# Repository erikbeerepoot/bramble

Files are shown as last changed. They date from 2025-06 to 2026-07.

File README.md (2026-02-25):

# Bramble

LoRa sensor and actuator network for farm monitoring, built on RP2040.

Hub-and-spoke architecture: a central hub manages the network while nodes collect sensor data (temperature, humidity) and control actuators (irrigation valves). LoRa provides long-range wireless with reliable delivery guarantees.

## Hardware

- Adafruit Feather RP2040 LoRa (SX1276, 915 MHz)
- MT25QL01GBBB 128MB external flash for sensor data storage
- STM32L010 PMU for power management and sleep

## Building

Requires the Pico SDK. CMake is bundled at `~/.pico-sdk/cmake/v3.31.5/bin/cmake`.

```bash
# Build a specific variant
cmake -B build -DHARDWARE_VARIANT=SENSOR
cmake --build build -j8

# Variants: SENSOR, IRRIGATION, CONTROLLER, HUB, GENERIC, ALL
```

Each variant produces a named executable (e.g. `bramble_sensor.uf2`).

```bash
# Run tests
cmake -B build -DBUILD_TESTS=ON
cmake --build build -j8
```

### Flashing

Hold BOOTSEL and connect via USB, then copy the `.uf2` file. Or use OpenOCD with a debug probe:

```bash
~/.pico-sdk/openocd/0.12.0+dev/openocd \
  -s ~/.pico-sdk/openocd/0.12.0+dev/scripts \
  -f interface/cmsis-dap.cfg -f target/rp2040.cfg \
  -c "adapter speed 5000" \
  -c "program build/bramble_sensor.elf verify reset exit"
```

## Architecture

```
[Sensor Nodes] --LoRa--> [Hub/Pico] --Serial--> [Raspberry Pi] --REST--> [Dashboard]
                               |                       |
                          128MB Flash              DuckDB
                        (local buffer)          (long-term storage)
```

### Firmware (`src/`)

- `modes/` - Application modes per hardware variant (sensor, irrigation, hub, etc.)
- `lora/` - SX1276 driver, message protocol, reliable delivery, routing
- `hal/` - Hardware abstraction (flash, NeoPixel, valves, SPI)
- `storage/` - 128MB circular flash buffer for sensor records
- `config/` - Persistent node/hub configuration

### API (`api/`)

Flask REST API on the Raspberry Pi. Receives sensor data from the hub over serial, stores in DuckDB.

```bash
cd api && uv sync && uv run app.py
```

### Dashboard (`dashboard/`)

React SPA for viewing sensor data, managing nodes, and organizing zones.

```bash
cd dashboard && npm install && npm run dev
```

## Setup

After cloning:

```bash
./setup.sh  # configures git hooks
```

See `CLAUDE.md` for development guidelines and `PLAN.md` for the roadmap.

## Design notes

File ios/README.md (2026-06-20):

# Bramble Valve Widget (iOS)

An iOS 18+ Home/Lock Screen **widget** to start and stop irrigation valves via the
Bramble REST API. Each valve gets a Run and a Stop button; tapping one fires an
**App Intent** that POSTs to the API directly from the widget process.

The north star is **time to task** — minimize the steps from intent to starting a
watering task. The Home Screen widget shows all configured valves (Run/Stop each); the
Lock Screen accessory widget shows your **primary** valves with a single toggle (tap to
run, tap to stop) for the fewest possible taps. See
[`../plans/ios_valve_widget.md`](../plans/ios_valve_widget.md) for the full design.

> **Status:** source + project definition are committed and the shared networking/
> storage layer type-checks against the SDK, but the project has **not been built**
> (this repo's CI and the dev machine that scaffolded it only have Command Line Tools,
> not full Xcode). First build must happen in Xcode on a Mac — expect to resolve minor
> SDK/signing issues there.

## Layout

```
ios/
  project.yml                       XcodeGen project definition
  Shared/                           compiled into BOTH targets
    BrambleAPIClient.swift          URLSession client (runValve / stopValve / health)
    KeychainStore.swift             secrets in Keychain (shared access group)
    AppSettings.swift               base URL + valve list (App Group defaults)
    ValveConfig.swift               a configured valve (label, device id, valve, duration)
    ValveStateStore.swift           optimistic per-valve UI state
  BrambleWidget/                    host app (settings screen)
    BrambleWidgetApp.swift, SettingsView.swift
    BrambleWidget.entitlements
  BrambleWidgetExtension/           widget extension
    BrambleWidgetBundle.swift       registers both widgets
    ValveWidget.swift               Home Screen widget (all valves, Run/Stop)
    ValveLockScreenWidget.swift     Lock Screen accessory widget (primary valves, toggle)
    ValveControlIntents.swift       RunValveIntent / StopValveIntent / ToggleValveIntent
    Info.plist, BrambleWidgetExtension.entitlements
```

## Generate & open the project

The `.xcodeproj` is generated, not committed (avoids churn in `project.pbxproj`):

```bash
brew install xcodegen      # one-time
cd ios
xcodegen generate          # writes BrambleWidget.xcodeproj
open BrambleWidget.xcodeproj
```

## One-time Xcode / Apple setup (cannot be scripted here)

1. **Signing team** — select your Apple Developer team on *both* the `BrambleWidget`
   and `BrambleWidgetExtension` targets (Signing & Capabilities), or set
   `DEVELOPMENT_TEAM` in `project.yml`. A **paid** account is effectively required —
   free signing expires every 7 days, impractical for an always-present widget.
2. **App Group** — both targets already declare `group.ag.bramble.widget` in their
   entitlements. Register the group on your developer account / let Xcode auto-create it.
3. **Keychain Sharing** — both entitlements list `$(AppIdentifierPrefix)ag.bramble.widget`
   so the app and widget read the same secrets. Confirm the capability is enabled.
4. If you change the bundle id prefix, update it in `project.yml`, both `.entitlements`,
   and `AppGroup.identifier` in `Shared/AppSettings.swift`.

## Cloudflare Access (so the widget can reach the API)

`api.bramble.ag` sits behind Cloudflare Access. A widget is not a browser and can't do
the interactive login, so:

1. In Cloudflare Zero Trust, create an **Access service token**.
2. Add an Access policy on `api.bramble.ag` that allows that service token.
3. Enter the token's **Client ID** and **Client Secret** in the app's settings screen
   (stored in the Keychain, sent as `CF-Access-Client-Id` / `CF-Access-Client-Secret`).

## API token

The backend gates the valve endpoints on a bearer token when `API_TOKEN` is set
(see [`../api/docs/API.md`](../api/docs/API.md#authentication)). Enter the same token
in the app's settings screen — it is sent as `Authorization: Bearer <token>`.

## Configure & use

1. Launch the app, fill in **Base URL** (`https://api.bramble.ag`), the **API token**,
   and the **CF-Access** client id/secret. Tap **Test Connection** (hits `/api/health`).
2. Add one or more **valves**: a label, the node's `device_id` (64-bit hardware id),
   the 0-based valve index, and a default run duration. Toggle **Show on Lock Screen**
   for the one or two valves you reach for most. Tap **Save**.
3. Add the **Valves** widget to your Home Screen — tap a valve's drop icon to run it for
   its default duration, or the stop icon to close it.
4. Add the **Valves (Lock Screen)** accessory widget to your Lock Screen — it shows your
   primary valves; one tap runs an idle valve, another stops it. Circular fits one valve,
   rectangular up to two, inline shows a running-count summary.

## Known limitations / follow-ups

- Widget state is **optimistic** (written locally on tap); it does not yet reflect true
  hardware state. Follow-up: poll `GET /api/tasks/{task_id}` or node status.
- App Intent execution from a widget has a short time budget — calls are fire-and-forget.
- Backend v1 trusts the `Cf-Access-Jwt-Assertion` header without verifying its signature
  (it only arrives via the tunnel). Hardening follow-up: verify against Cloudflare JWKS.

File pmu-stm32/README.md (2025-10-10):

# Bramble PMU (STM32)

Power Management Unit for the Bramble flower farm monitoring system.

## Hardware
- **MCU**: STM32L010F4 (20-pin TSSOP, ultra-low-power)
- **Features**:
  - Bicolour LED status indication (common anode)
  - DC/DC converter control via MOSFET
  - UART communication
  - Power management and battery monitoring

## Build System

### Using STM32CubeIDE
1. Import this directory as an existing project
2. Build and flash using IDE

### Using Make (if configured)
```bash
make
make flash
```

## Getting Started

Current status: Basic LED blink demo

## Pin Configuration

| Function | Pin | GPIO | Notes |
|---|-----|---|---|
| LED Red | 10  | PA4 | Common anode bicolour LED|
| LED Green | 11  | PA5 | Common anode bicolour LED|
| UART TX | 8 | PA2 | USART2_TX |
| UART RX | 9 | PA3 | USART2_RX |
| DC/DC Enable | 7 | PA1 | MOSFET gate control |

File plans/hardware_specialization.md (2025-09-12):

# Hardware Specialization Architecture

## Overview
This plan describes how to extend the Bramble platform to support specialized hardware variants while maintaining the flexibility for any node to act as a hub. The primary use cases are irrigation control nodes and a controller node that typically serves as the hub.

## Design Principles
1. **Role Flexibility**: Hub/node is a runtime role, not tied to hardware
2. **Hardware Specialization**: Different binaries for different hardware configurations
3. **Modularity**: Clean separation between network role and hardware capabilities
4. **Efficiency**: Only include code needed for specific hardware

## Architecture

### Build System
Create specialized executables based on hardware configuration:
```
bramble_controller.uf2  # UI, scheduling, defaults to hub role
bramble_irrigation.uf2  # Valve control + soil sensors, defaults to node role
bramble_sensor.uf2      # Temperature/humidity only, defaults to node role
bramble_generic.uf2     # Basic node, any sensors, defaults to node role
```

### Role Selection
Each binary has a build-time default role that makes sense for its hardware:
```cpp
// Set at compile time via CMake
#ifdef HARDWARE_CONTROLLER
    constexpr bool DEFAULT_IS_HUB = true;   // Controllers usually run as hub
#else
    constexpr bool DEFAULT_IS_HUB = false;  // Field devices usually nodes
#endif
```

## Implementation Plan

### 1. Refactor Mode Class Hierarchy
```
ApplicationMode (base)
├── NetworkRole (built into ApplicationMode)
│   ├── Hub functionality (if is_hub_)
│   └── Node functionality (if !is_hub_)
└── Derived Hardware Modes
    ├── ControllerMode   # UI, scheduling, commands
    ├── IrrigationMode   # Valves, soil sensors
    └── SensorMode       # Basic sensors only
```

### 2. CMake Build Configuration
```cmake
# Hardware variant selection
set(HARDWARE_VARIANT "GENERIC" CACHE STRING "Hardware variant type")
set_property(CACHE HARDWARE_VARIANT PROPERTY STRINGS 
    GENERIC CONTROLLER IRRIGATION SENSOR)

# Create specialized executables
if(HARDWARE_VARIANT STREQUAL "CONTROLLER")
    add_executable(bramble_controller
        main.cpp
        src/modes/controller_mode.cpp
        ${COMMON_SOURCES}
        ${HUB_SOURCES}  # Include hub capability
    )
    target_compile_definitions(bramble_controller PRIVATE
        HARDWARE_CONTROLLER=1
        DEFAULT_IS_HUB=1  # Controllers default to hub role
    )
elseif(HARDWARE_VARIANT STREQUAL "IRRIGATION")
    add_executable(bramble_irrigation
        main.cpp
        src/modes/irrigation_mode.cpp
        src/hal/valve_controller.cpp
        src/hal/soil_moisture.cpp
        ${COMMON_SOURCES}
        ${HUB_SOURCES}  # Include hub capability
    )
    target_compile_definitions(bramble_irrigation PRIVATE
        HARDWARE_IRRIGATION=1
        DEFAULT_IS_HUB=0  # Field devices default to node role
    )
endif()
```

### 3. Unified Main Entry Point
```cpp
// main.cpp - replaces bramble.cpp
int main() {
    stdio_init_all();
    
    // Use build-time default role
    constexpr bool is_hub = DEFAULT_IS_HUB;
    
    // Hardware initialization
    SX1276 lora(SPI_PORT, PIN_CS, PIN_RST, PIN_DIO0);
    NeoPixel led;
    
    if (!initializeHardware(lora, led)) {
        panic("Hardware initialization failed!");
    }
    
    // Show role with LED pattern
    if (is_hub) {
        led.set(0, 0, 255);  // Blue for hub
        printf("Starting as HUB\n");
    } else {
        led.set(0, 255, 0);  // Green for node
        printf("Starting as NODE\n");
    }
    
    // Create appropriate mode based on compile-time config
    #ifdef HARDWARE_CONTROLLER
        ControllerMode mode(messenger, lora, led, address_manager, 
                           hub_router, network_stats, is_hub);
    #elif HARDWARE_IRRIGATION
        IrrigationMode mode(messenger, lora, led, address_manager,
                           hub_router, network_stats, is_hub);
    #elif HARDWARE_SENSOR
        SensorMode mode(messenger, lora, led, address_manager,
                       hub_router, network_stats, is_hub);
    #else
        GenericMode mode(messenger, lora, led, address_manager,
                        hub_router, network_stats, is_hub);
    #endif
    
    mode.run();
    return 0;
}
```

### 4. Mode Implementations

#### Base ApplicationMode Changes
```cpp
class ApplicationMode {
protected:
    const bool is_hub_;  // Set at construction, never changes
    
public:
    ApplicationMode(ReliableMessenger& messenger, SX1276& lora,
                   NeoPixel& led, AddressManager* address_manager,
                   HubRouter* hub_router, NetworkStats* network_stats,
                   bool is_hub)
        : messenger_(messenger), lora_(lora), led_(led),
          address_manager_(address_manager), hub_router_(hub_router),
          network_stats_(network_stats), is_hub_(is_hub) {
        
        // Only initialize hub components if running as hub
        if (is_hub_ && !address_manager_) {
            address_manager_ = new AddressManager();
            hub_router_ = new HubRouter(messenger_, *address_manager_);
        }
    }
    
    void run() {
        // Common initialization
        onStart();
        
        // Role-specific initialization
        if (is_hub_) {
            printf("Initializing hub services...\n");
            address_manager_->initialize();
            // Hub doesn't need registration
        } else {
            printf("Initializing node services...\n");
            // Attempt registration with hub
            attemptRegistration();
        }
        
        // Main loop (same for both roles)
        while (true) {
            // ... existing main loop
        }
    }
};
```

#### ControllerMode
```cpp
class ControllerMode : public ApplicationMode {
private:
    // Controller-specific hardware
    UIManager ui_;
    ScheduleEngine scheduler_;
    ZoneManager zones_;
    
public:
    using ApplicationMode::ApplicationMode;  // Inherit constructor
    
    void onStart() override {
        // Set capabilities
        capabilities_ = CAP_CONTROLLER | CAP_SCHEDULING;
        node_type_ = NODE_TYPE_CONTROLLER;
        
        // Initialize UI (buttons, display)
        ui_.initialize();
        
        // Load schedules and zones
        scheduler_.loadSchedules();
        zones_.loadConfiguration();
        
        // LED pattern for controller
        if (is_hub_) {
            led_pattern_ = std::make_unique<PulsePattern>(led_, 0, 0, 255); // Blue pulse
        } else {
            // Unlikely but possible - controller as node
            led_pattern_ = std::make_unique<BlinkPattern>(led_, 255, 0, 255); // Purple blink
        }
        
        // Add periodic tasks
        task_manager_.addTask(
            [this](uint32_t time) { checkSchedules(); },
            1000,  // Check every second
            "Schedule Check"
        );
        
        task_manager_.addTask(
            [this](uint32_t time) { updateUI(); },
            100,  // Update UI every 100ms
            "UI Update"
        );
    }
    
    void handleUIEvent(UIEvent event) {
        switch (event.type) {
            case UI_BUTTON_PRESS:
                handleButtonPress(event.button_id);
                break;
            case UI_ENCODER_TURN:
                handleEncoderTurn(event.delta);
                break;
        }
    }
};
```

#### IrrigationMode
```cpp
class IrrigationMode : public ApplicationMode {
private:
    ValveController valve_controller_;
    SoilMoistureSensor soil_sensor_;
    WaterUsageTracker water_tracker_;
    
public:
    using ApplicationMode::ApplicationMode;
    
    void onStart() override {
        capabilities_ = CAP_VALVE_CONTROL | CAP_SOIL_MOISTURE;
        node_type_ = NODE_TYPE_HYBRID;
        
        // Initialize hardware
        valve_controller_.initialize();
        soil_sensor_.initialize();
        
        // LED pattern
        if (is_hub_) {
            // Emergency hub mode - alternating blue/green
            led_pattern_ = std::make_unique<AlternatePattern>(led_, 0, 255, 0, 0, 0, 255);
            logger_.warn("Irrigation node running as emergency hub!");
        } else {
            // Normal operation - green heartbeat
            led_pattern_ = std::make_unique<HeartbeatPattern>(led_, 0, 255, 0);
        }
        
        // Add sensor reading task
        task_manager_.addTask(
            [this](uint32_t time) { readAndReportSensors(); },
            30000,  // Every 30 seconds
            "Sensor Reading"
        );
    }
    
    void onActuatorCommand(const ActuatorPayload* payload) override {
        if (payload->actuator_type == ACTUATOR_VALVE) {
            uint8_t valve_id = payload->params[0];
            
            if (payload->command == CMD_TURN_ON) {
                valve_controller_.openValve(valve_id);
                water_tracker_.startFlow(valve_id);
            } else if (payload->command == CMD_TURN_OFF) {
                valve_controller_.closeValve(valve_id);
                auto usage = water_tracker_.stopFlow(valve_id);
                reportWaterUsage(valve_id, usage);
            }
        }
    }
};
```

### 5. Configuration Extensions

#### Controller Configuration
```cpp
class ControllerConfig : public ConfigBase {
    struct Zone {
        char name[32];
        uint16_t node_addresses[MAX_NODES_PER_ZONE];
        uint8_t valve_ids[MAX_VALVES_PER_ZONE];
        uint8_t node_count;
    };
    
    struct Schedule {
        uint8_t zone_id;
        uint32_t start_time;  // Seconds since midnight
        uint32_t duration_seconds;
        uint8_t days_of_week;  // Bitmask
        bool enabled;
    };
    
    Zone zones[MAX_ZONES];
    Schedule schedules[MAX_SCHEDULES];
    uint8_t zone_count;
    uint8_t schedule_count;
};
```

### 6. Directory Structure
```
src/
├── main.cpp                      # Unified entry point
├── modes/
│   ├── application_mode.h/cpp    # Base class with role support
│   ├── controller_mode.h/cpp     # Controller specialization
│   ├── irrigation_mode.h/cpp     # Irrigation specialization
│   ├── sensor_mode.h/cpp         # Sensor-only specialization
│   └── generic_mode.h/cpp        # Generic node
├── hal/
│   ├── valve_controller.h/cpp    # Existing valve control
│   ├── soil_moisture.h/cpp       # Soil sensor interface
│   ├── ui_manager.h/cpp          # Buttons, display, encoder
│   └── ...
├── services/
│   ├── schedule_engine.h/cpp     # Scheduling logic
│   ├── zone_manager.h/cpp        # Zone management
│   └── water_usage_tracker.h/cpp # Track water consumption
└── config/
    ├── controller_config.h/cpp    # Controller settings
    └── irrigation_config.h/cpp    # Irrigation settings
```

## Build Examples

```bash
# Build controller (defaults to hub)
cmake -B build -DHARDWARE_VARIANT=CONTROLLER
cmake --build build
# Output: bramble_controller.uf2

# Build irrigation node (defaults to node)
cmake -B build -DHARDWARE_VARIANT=IRRIGATION  
cmake --build build
# Output: bramble_irrigation.uf2

# Build basic sensor (defaults to node)
cmake -B build -DHARDWARE_VARIANT=SENSOR
cmake --build build  
# Output: bramble_sensor.uf2
```

## Deployment Example

```
Farm Network:
├── Greenhouse Controller      # bramble_controller.uf2 (running as hub)
│   ├── Display + Buttons     
│   ├── Schedules: 6AM, 6PM
│   └── 3 Zones configured
│
├── Irrigation Node 1         # bramble_irrigation.uf2 (running as node)
│   ├── Valves: 1, 2
│   ├── Soil Moisture: 45%
│   └── Address: 0x0001
│
├── Irrigation Node 2         # bramble_irrigation.uf2 (running as node)
│   ├── Valves: 1, 2  
│   ├── Soil Moisture: 38%
│   └── Address: 0x0002
│
└── Weather Station          # bramble_sensor.uf2 (running as node)
    ├── Temperature: 24°C
    ├── Humidity: 65%
    └── Address: 0x0003
```

## Future Extensions

1. **Configuration UI**: Add USB serial commands to change settings
2. **Role Override**: Button combination at boot to toggle role
3. **Failover**: Automatic hub election if primary hub fails
4. **OTA Updates**: Different firmware for different hardware types

This architecture provides specialized functionality while keeping role selection simple through build-time defaults.

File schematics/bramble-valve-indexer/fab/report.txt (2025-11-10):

Warning: Width correction constrained.  The width correction value must be in the range of [0.000001 mm; -0.000002 mm] for the current design rules.
Plotted to '/Users/erikbeerepoot/Code/bramble/schematics/bramble/bramble_valve_indexer/bramble_valve_indexer-F_Cu.gbr'.
Plotted to '/Users/erikbeerepoot/Code/bramble/schematics/bramble/bramble_valve_indexer/bramble_valve_indexer-B_Cu.gbr'.
Plotted to '/Users/erikbeerepoot/Code/bramble/schematics/bramble/bramble_valve_indexer/bramble_valve_indexer-F_Paste.gbr'.
Plotted to '/Users/erikbeerepoot/Code/bramble/schematics/bramble/bramble_valve_indexer/bramble_valve_indexer-B_Paste.gbr'.
Plotted to '/Users/erikbeerepoot/Code/bramble/schematics/bramble/bramble_valve_indexer/bramble_valve_indexer-F_Silkscreen.gbr'.
Plotted to '/Users/erikbeerepoot/Code/bramble/schematics/bramble/bramble_valve_indexer/bramble_valve_indexer-B_Silkscreen.gbr'.
Plotted to '/Users/erikbeerepoot/Code/bramble/schematics/bramble/bramble_valve_indexer/bramble_valve_indexer-F_Mask.gbr'.
Plotted to '/Users/erikbeerepoot/Code/bramble/schematics/bramble/bramble_valve_indexer/bramble_valve_indexer-B_Mask.gbr'.
Plotted to '/Users/erikbeerepoot/Code/bramble/schematics/bramble/bramble_valve_indexer/bramble_valve_indexer-Edge_Cuts.gbr'.
Created Gerber job file '/Users/erikbeerepoot/Code/bramble/schematics/bramble/bramble_valve_indexer/bramble_valve_indexer-job.gbrjob'.
Info: Done.
Info: Done.

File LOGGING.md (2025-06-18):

# Bramble Logging System

## Quick Start

### 1. Add Logger to Your Class
```cpp
// In your .h file
#include "hal/logger.h"

class MyClass {
private:
    Logger logger_;
public:
    MyClass() : logger_("MODULE_NAME") {}
};
```

### 2. Use Logging Methods
```cpp
// Replace old printf statements:
printf("Error: failed to connect\n");
logger_.error("Failed to connect");

// Different log levels:
logger_.error("Critical error occurred");     // Always shown (unless LOG_NONE)
logger_.warn("Something suspicious");         // Warnings and above
logger_.info("General information");          // Info level and above  
logger_.debug("Detailed debug info");         // Debug level only
```

### 3. Set Log Levels
```cpp
// In main():
Logger::setLogLevel(LOG_DEBUG);   // Show everything (demo mode)
Logger::setLogLevel(LOG_WARN);    // Production: warnings/errors only
Logger::setLogLevel(LOG_ERROR);   // Critical errors only
Logger::setLogLevel(LOG_NONE);    // No logging (ultra low power)
```

## Output Format
```
INFO [FLASH]: Initialized with 8 MB flash
WARN [FLASH]: Write retry 2/3 at offset 0x007FF000
ERR [CONFIG]: Primary config magic mismatch (found 0x12345678, expected 0xBEEF1234)
DBG [LORA]: Message sent to 0x0001
```

## Power Optimization

### Battery-Powered Nodes
```cpp
// In main() for battery nodes:
Logger::setLogLevel(LOG_ERROR);        // Minimal logging
Logger::setUsbCheckEnabled(true);      // Only log when USB connected
```

### Development/Demo
```cpp
// In main() for development:
Logger::setLogLevel(LOG_DEBUG);        // Full verbosity
Logger::setUsbCheckEnabled(false);     // Always log
```

## Migration Guide

### Old Code:
```cpp
printf("Flash write failed at offset 0x%08x\n", offset);
```

### New Code:
```cpp
class Flash {
private:
    Logger logger_;
public:
    Flash() : logger_("FLASH") {}
    
    void someMethod() {
        logger_.error("Write failed at offset 0x%08lx", offset);
    }
};
```

## Recommended Module Names
- `"MAIN"` - Main application
- `"FLASH"` - Flash operations  
- `"CONFIG"` - Configuration management
- `"LORA"` - LoRa radio operations
- `"NETWORK"` - Network/routing
- `"SENSOR"` - Sensor readings
- `"ACTUATOR"` - Actuator control

## Best Practices

1. **Use appropriate levels**:
   - `error()`: System failures, critical issues
   - `warn()`: Retry attempts, recoverable issues  
   - `info()`: Normal operations, status updates
   - `debug()`: Detailed internal state

2. **Keep module names short** (8 chars max for clean formatting)

3. **No newlines needed** (logger adds them automatically)

4. **Production deployment**:
   ```cpp
   #ifdef PRODUCTION_BUILD
   Logger::setLogLevel(LOG_ERROR);
   #else  
   Logger::setLogLevel(LOG_DEBUG);
   #endif
   ```

## Power Impact

**LOG_DEBUG**: ~2-5mA extra power consumption  
**LOG_INFO**: ~1-2mA extra power consumption  
**LOG_WARN**: ~0.5mA extra power consumption  
**LOG_ERROR**: ~0.1mA extra power consumption  
**LOG_NONE**: Zero logging overhead

For **battery-powered farm sensors**, use `LOG_ERROR` in production!

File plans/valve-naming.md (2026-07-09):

# Feature: Per-valve naming

## Context
A node can have multiple valves (identified only by 0-based index, `0 ≤ valve < valve_count`).
Today the dashboard shows bare "Valve 1 / Valve 2" and the iOS widget has a **local-only**
`label` per valve that nothing else knows about. Users need to give valves real names
("North Bed", "Greenhouse Row 3") that are consistent across the dashboard and iOS.

**Decision:** server is the source of truth. Names live in the API DB, are editable from the
dashboard and iOS, and the iOS widget's display name syncs from the server.

## Data model (mirrors `node_metadata`)
New DuckDB table (add to `SCHEMA` in `api/database.py`; `CREATE TABLE IF NOT EXISTS` runs on
every `init_db`, so existing DBs pick it up — no `_migrate_schema` entry needed):
```sql
CREATE TABLE IF NOT EXISTS valve_metadata (
    device_id UBIGINT NOT NULL,
    valve_index INTEGER NOT NULL,
    name VARCHAR,
    updated_at INTEGER NOT NULL,
    PRIMARY KEY (device_id, valve_index)
);
```
Name only (KISS — no notes/zone; valves already belong to a node).

## Backend (`api/database.py`, `api/app.py`)
- DB methods mirroring `get_node_metadata` / `get_all_node_metadata` / `update_node_metadata`
  (`database.py:877-979`):
  - `get_valve_metadata(device_id, valve_index)` → dict or None
  - `get_all_valve_metadata()` → `{device_id: {valve_index: {valve, name, updated_at}}}`
    (single query, used to embed names in `/api/nodes` without N queries)
  - `update_valve_metadata(device_id, valve_index, name)` → upsert, returns the row
- Endpoints mirroring node-metadata endpoints (`app.py:716-779`):
  - `GET  /api/nodes/<device_id>/valves/<valve_id>/metadata` → `{device_id, valve, name, updated_at}`
    (empty struct when unset)
  - `PUT  /api/nodes/<device_id>/valves/<valve_id>/metadata` → body `{ "name": "North Bed" }`;
    validate `0 ≤ valve_id < _node_valve_count(device_id)` (reuse helper at `app.py:226-253`)
- Surface names in `list_nodes` (both hub path ~`app.py:441` and `_build_nodes_from_database`
  ~`app.py:161`): add `node_dict['valves'] = {str(index): name, ...}` from one
  `get_all_valve_metadata()` call, so dashboard + iOS get names in the existing nodes fetch.

## Dashboard (`dashboard/`)
- `src/types/index.ts` — add `valves?: Record<string, string>` to the node type; `ValveMetadata`.
- `src/api/client.ts` — `updateValveMetadata(deviceId, valveIndex, name)` (PUT). Names for display
  come from the node payload's `valves` map (no extra fetch).
- `src/components/IrrigationControl.tsx` — replace hardcoded `Valve {i+1}` in the run controls,
  schedule builder, and schedule rows with the server name when present, falling back to
  `Valve {i+1}`.
- Editing: small inline editor (pattern from `NodeNameEditor.tsx`) — a pencil next to each valve
  row that PUTs the name and refreshes.

## iOS (`ios/`) — user builds/tests in Xcode
- `Shared/BrambleAPIClient.swift` — add `updateValveMetadata` (PUT) and read the `valves` map from
  the nodes response (or a per-valve GET).
- `Shared/ValveConfig.swift` — the display name derives from the server name; keep `label` as a
  local override only if the server name is absent (server = source of truth).
- `BrambleWidgetExtension/ValveWidget.swift` — show the server name.
- `BrambleWidget/SettingsView.swift` — when configuring a valve, prefill/sync the name from the
  server; editing the name writes back via `updateValveMetadata`.

## Rollout
1. **PR 1 — backend** (`database.py`, `app.py`): table, methods, endpoints, `/api/nodes` embed.
   Verifiable independently (curl the endpoints on the hub).
2. **PR 2 — dashboard**: display + edit.
3. **PR 3 — iOS**: client + widget + settings (user builds in Xcode).

## Verification
- Backend: `PUT /api/nodes/<id>/valves/0/metadata {"name":"North Bed"}` → 200; `GET` returns it;
  `/api/nodes` shows `"valves":{"0":"North Bed"}`; out-of-range valve id → 400.
- Dashboard: valve rows/schedules show the name; editing persists across reload.
- iOS: widget shows the server name; renaming in settings reflects on the dashboard.

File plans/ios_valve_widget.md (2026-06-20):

# iOS Valve Widget

## Goal

An **iOS Home Screen / Lock Screen widget** that lets the user start and stop irrigation
valves directly from a button tap, by calling the existing Bramble REST API
(`api.bramble.ag`). No companion screen interaction required for the common case —
tap a valve button in the widget → valve runs for a preset duration; tap stop → valve
closes.

## North star: time to task

The guiding metric is **time to task** — minimizing the time from intent to starting/
managing a watering task. Automation's value is not doing the task yourself, but you still
have to *start and manage* it, so that step must be near-instant. This is why the primary
surfaces are widgets (no app launch), with Control Center / Action Button / Siri as future
accelerators, and why the host app must launch fast and stay minimal.

**Surfaces, ranked by time-to-task:** Action Button (1 press) > Control Center control
(swipe+tap) > Lock Screen widget/control (tap, no unlock) > Home Screen widget (multi-valve
grid) > Siri/App Shortcuts > the app itself. Deployment target is **iOS 18** to keep the
Controls API (Control Center / Action Button) available for a later phase.

## Current state

- **No Apple code exists.** Only client is the React/Vite dashboard (`dashboard/`).
- **Valve API is ready** (`api/app.py`):
  - Start: `POST /api/nodes/{device_id}/valve` → `{"valve": 0, "duration_seconds": 900}` → `202` `{status, task_id, command_id, ...}`. `duration_seconds` 1–7200; `valve` range-checked against node valve count.
  - Stop: `POST /api/nodes/{device_id}/valve/stop` → `{"valve": 0}` → `202`.
  - Status (optional): `GET /api/tasks/{task_id}`, `GET /api/health`.
- **Auth today**: none at the Flask layer (`api/docs/API.md`: "No authentication required").
  Production is gated only by **Cloudflare Access** (cookie/JWT); the dashboard rides that
  cookie via `credentials: 'include'` (`dashboard/src/api/client.ts:49`). CORS is locked to
  the dashboard origin (`app.py:30`).

## Auth design (decided: bearer token in API)

Add an app-controlled, revocable bearer token at the Flask layer, while keeping the
dashboard's existing Cloudflare-Access cookie flow working.

**Backend (`api/`):**
- New config `API_TOKEN = os.getenv('API_TOKEN', '')` in `config.py`. Empty ⇒ enforcement
  off (preserves local/dev "no auth, local network" behavior).
- New `@require_token` decorator (small `auth.py` module). When `API_TOKEN` is set, a request
  is allowed if **either**:
  1. `Authorization: Bearer <token>` matches `API_TOKEN` (constant-time compare) — the widget path, **or**
  2. the request carries Cloudflare's `Cf-Access-Jwt-Assertion` header — i.e. an
     already-CF-Access-authenticated dashboard user. (v1 trusts the edge since Flask is only
     reachable through the tunnel; hardening note below to verify the JWT against CF JWKS.)
- Apply `@require_token` to the two valve routes for v1 (`run_valve`, `stop_valve`). The
  decorator is reusable for the other 17 mutating routes later.
- Return `401` JSON on failure. Keep CORS as-is (widget is not a browser; no preflight).

**Cloudflare (user-side config, documented — not code):**
- Create a **service token** in Cloudflare Access and a policy allowing it on
  `api.bramble.ag`, so the widget's non-browser request passes the edge. Widget sends
  `CF-Access-Client-Id` + `CF-Access-Client-Secret` (edge) **and** `Authorization: Bearer`
  (Flask). Defense in depth: both the edge and the app gate the request.
- Simpler alternative (documented, not chosen): a CF Access **bypass** rule for the valve
  paths, leaving the Flask bearer token as the sole gate. Less defense-in-depth.

**Secrets on device:** API token (and CF service-token id/secret) stored in the **Keychain**,
shared with the widget extension via an **App Group** + keychain access group. Never hardcoded.

## iOS app design

Greenfield Xcode project under `ios/BrambleWidget/`. Three pieces:

1. **Host app target** (`BrambleWidget`) — minimal SwiftUI app whose only jobs are:
   - Settings screen: API base URL, bearer token, CF service-token id/secret → Keychain.
   - Valve configuration: an editable list of `{ label, device_id, valve, default_duration }`
     entries persisted to the shared App Group (`UserDefaults(suiteName:)`). v1 may seed from
     a hardcoded list and allow edits.
   - "Test connection" button hitting `GET /api/health`.
2. **Widget extension target** (`BrambleWidgetExtension`, WidgetKit) — **iOS 17+ interactive
   widget**:
   - Timeline shows the configured valves as a grid of buttons with current state
     (idle / running / error).
   - Each Run/Stop button is a SwiftUI `Button(intent:)` bound to an **App Intent**
     (`RunValveIntent`, `StopValveIntent`). The intent performs the network POST (App Intents
     get a few seconds of execution — enough for one request) and calls
     `WidgetCenter.shared.reloadAllTimelines()`.
3. **Shared layer** (Swift package or shared group) — used by both targets:
   - `BrambleAPIClient`: `URLSession`-based, mirrors `runValve`/`stopValve`; injects
     `Authorization: Bearer` + CF service-token headers; decodes the `202` response.
   - `KeychainStore` + `ValveConfig` (Codable, App Group).

**Widget interaction model:** iOS 17 `AppIntent` + `Button(intent:)` is the only way to act
from a widget without launching the app. Pre-iOS-17 fallback is out of scope (deep-link into
app only) — target iOS 17+.

## Touch points

1. `api/config.py` — add `API_TOKEN`.
2. `api/auth.py` (new) — `require_token` decorator + constant-time compare + CF assertion check.
3. `api/app.py` — import + decorate `run_valve`, `stop_valve`.
4. `api/tests/` — tests: no token configured ⇒ allowed; token set + valid bearer ⇒ allowed;
   token set + missing/wrong bearer ⇒ 401; token set + CF assertion header ⇒ allowed.
5. `api/docs/API.md` + `api/README.md` — document `API_TOKEN`, the bearer header, and the
   Cloudflare service-token setup steps.
6. `api/docker-compose.prod.yml` / systemd env — wire `API_TOKEN` (user adds the secret).
7. `ios/BrambleWidget/` (new) — Xcode project: host app, widget extension, shared layer.
8. `ios/README.md` (new) — build/signing/Cloudflare/Keychain setup, App Group id.

## Build / signing notes

- WidgetKit interactive buttons require **iOS 17+** and the **App Intents** framework.
- A widget cannot ship alone — it needs a host app target.
- On-device install / TestFlight needs a **paid Apple Developer account** ($99/yr); free
  signing resigns every 7 days (impractical for an always-present widget).
- Xcode project generation: hand-authored `.xcodeproj` (or `xcodegen` if available). The repo
  CI does not build iOS; this target is built locally in Xcode.

## Risks / notes

- **Auth correctness is the crux.** Must verify the dashboard still works after `@require_token`
  lands (CF assertion path). Test against staging before pointing the widget at prod.
- v1 trusts the `Cf-Access-Jwt-Assertion` header without verifying its signature. Acceptable
  because Flask is only reachable via the tunnel; **hardening follow-up**: validate the JWT
  against Cloudflare's JWKS (`/cdn-cgi/access/certs`).
- App Intent execution budget is short; keep the request fast and fire-and-forget. Optional
  `task_id` polling for confirmed state is a follow-up, not v1.
- Token is a bearer secret — anyone holding it can drive valves. Keychain-only storage; make
  it rotatable via the `API_TOKEN` env.

## Phasing

- **Phase 1 (backend):** ✅ **DONE.** config `API_TOKEN` + `auth.py` `require_token` +
  decorated valve routes + `tests/test_auth.py` + docs (API.md/README/compose). Auth logic
  verified (7/7 branches) in a throwaway Flask harness; full pytest suite to run in the
  project's uv env.
- **Phase 2 (iOS shared layer + host app):** ✅ **DONE (unbuilt).** `Shared/` (API client,
  Keychain, settings, valve config, state store) + host app (settings screen). Shared layer
  type-checks against the SDK.
- **Phase 3 (Home Screen widget):** ✅ **DONE (unbuilt).** WidgetKit widget + `Button(intent:)`
  + `RunValveIntent`/`StopValveIntent` + optimistic state display. `project.yml`, Info.plist,
  entitlements committed. **First build must happen in Xcode** (this env has CLT only — no
  iOS SDK / xcodebuild). Source parses clean; expect minor SDK/signing fixups in Xcode.
- **Phase 3b (Lock Screen widget + primary-valve model):** ✅ **DONE (unbuilt).** Deployment
  target bumped to iOS 18. `ValveConfig.isPrimary` (+ backward-compatible decoding) and
  `AppSettings.primaryValves`; settings toggle to mark primaries. `ValveLockScreenWidget`
  supports `.accessoryCircular` / `.accessoryRectangular` / `.accessoryInline`, driven by a
  single-button `ToggleValveIntent` (run-if-idle / stop-if-running) for tiny surfaces.
- **Phase 4 (next time-to-task surfaces):** Control Center + Action Button (`ControlWidget`,
  iOS 18) for the primary valve; Siri / App Shortcuts (`AppShortcutsProvider`) over the
  existing intents.
- **Phase 5 (follow-up):** CF JWKS signature verification; `task_id`/node-status polling for
  authoritative widget state; richer multi-node config UI.

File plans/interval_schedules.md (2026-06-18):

# Interval Schedules

## Goal

Support recurring interval watering, e.g. **"run valve N every 2 hours for 15 minutes,
6am–6pm"** — not just the current fixed daily time-of-day windows.

## Current state

A `ScheduleEntry` (`pmu-stm32/Core/Inc/pmu_protocol.h:114`) is a wall-clock calendar
trigger only:

```cpp
uint8_t  hour, minute;   // absolute time of day
uint16_t duration;       // run length, seconds
DayOfWeek daysMask;      // days of week
uint8_t  valveId;
bool     enabled;
```

`minutesUntil()` / `findNextEntry()` match the next `hour:minute`; `isWithinWindow()`
checks a single fixed window. No concept of "every X". Today you'd fake it with 12
separate entries.

## Design

Extend the entry with an optional repeat, keeping legacy entries valid:

- `periodMinutes` (uint16) — interval between firings. **0 = legacy one-shot daily.**
- `windowMinutes` (uint16) — how long the repeating window runs from `hour:minute`.

`hour:minute` becomes the **window start**. Example "every 2h for 15min, 6am–6pm":
`start=06:00, periodMinutes=120, windowMinutes=720, duration=900, period>0`.

Firing logic (when `periodMinutes > 0`): inside `[start, start+windowMinutes]`, fire
when `(minutesSinceStart % periodMinutes) == 0`; run for `duration` seconds. Outside the
window, dormant. `minutesUntil` returns minutes to the next modulo boundary.

Backward compatible: `periodMinutes == 0` keeps exact current behavior.

## Touch points

1. **`ScheduleEntry`** struct + `SCHEDULE_ENTRY_SIZE` 7 → 11 (pmu_protocol.h). Add the
   two uint16 fields.
2. **Schedule logic** — `minutesUntil`, `isWithinWindow`, `overlapsWith` /
   `timeRangesOverlap` (pmu_protocol.cpp): branch on `periodMinutes`, modulo math.
3. **FRAM serialization** — `loadScheduleEntry` / `saveScheduleEntry`
   (persistent_storage.cpp); bump `FORMAT_VERSION` 3 → 4 (layout shift → re-init/wipe,
   which also lets fresh PMUs pick up the new 5-min wake default).
4. **PMU wire parse** — `handleSetSchedule` (pmu_protocol.cpp): payload now
   `index + 11 bytes`; length check `SCHEDULE_ENTRY_SIZE + 1`.
5. **RP2040 side** — `ScheduleEntry` struct + `addScheduleEntry` builder and the parser
   at `src/hal/pmu_protocol.cpp:482` (add the two fields to both ends of the wire).
6. **Hub / API / dashboard** — schedule authoring UI/endpoint to set period + window;
   validation; display "every Nm/Nh" form.

## Risks / notes

- FRAM format bump wipes persisted schedules + wake interval on existing PMUs — they
  re-init to defaults. Acceptable, but coordinate with a re-push of schedules from the hub.
- Overlap detection gets more involved for repeating windows (an interval entry occupies
  many sub-windows). Simplest first cut: treat an interval entry's whole `[start, start+window]`
  as occupied for overlap purposes.
- Keep `duration < periodMinutes*60` validation so a run can't bleed into the next firing.

## Scope estimate

PMU firmware (1–4) is the core, self-contained change. RP2040 (5) is mechanical.
Dashboard/API (6) is the larger surface. Ship PMU + RP2040 first behind period==0
default, then add UI.

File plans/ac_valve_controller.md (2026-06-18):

# AC Valve Controller (mains, always-awake)

Status: implemented on branch `feature/ac-valve-controller` (builds clean: IRRIGATION_AC v5/v4 +
IRRIGATION v5 regression). Full design: `~/.claude/plans/virtual-sniffing-hanrahan.md`.

## What it does
Supports **AC valves** (24 V AC) switched by **SSRs** — one GPIO per valve, high = open, held while
open (continuous power). Hardware is **mains-powered, pure-AC**, two valves on **GPIO36/38**. Because
an open SSR needs the GPIO driven, the node **never deep-sleeps** (deep sleep drops the rail → valve
closes). It stays awake and reacts to events live — which also makes it the ideal **master valve**
host: a one-off "run 5 min" mirrored to the master is picked up within a poll interval, not after a
30-min sleep TTL.

Firmware-only: the node registers as a normal IRRIGATION node (`valve_count=2`). Schedules still live
in PMU FRAM via `SET_SCHEDULE`, so the API, dashboard, and valve-group mirroring are unchanged — the
node just *reads and fires* schedules itself.

## Implemented
- **`ACValveDriver`** (`src/hal/valve_controller.h`): SSR GPIO on/off, `requiresContinuousPower()=true`.
- **`ValveController`** (`.cpp`): `#ifdef HARDWARE_IRRIGATION_AC` init builds AC drivers + GPIO out,
  skips H-bridge/indexer; `operateValve` skips indexer select/pulse for continuous-power drivers;
  `usesContinuousPower()` accessor.
- **Board pins** (`bramble_v5_pins.h`, `bramble_v4_pins.h`): under `HARDWARE_IRRIGATION_AC`,
  `NUM_VALVES=2`, `VALVE_PINS={36,38}`; DC defs kept in `#else`.
- **Build** (`CMakeLists.txt`): `IRRIGATION_AC` variant → `bramble_irrigation_ac*`, defines
  `HARDWARE_IRRIGATION=1` + `HARDWARE_IRRIGATION_AC=1`; in `ALL`. `main.cpp`: AC info log.
- **`IrrigationMode`** (all under `#ifdef HARDWARE_IRRIGATION_AC`, DC build byte-identical):
  - Never sleeps: `signalReadyForSleep()` keeps PMU awake and returns; `VALVE_ACTIVE` keeps awake and
    advances the SM instead of arming the PMU close-alarm.
  - `startAlwaysAwakeTasks()` registers periodic `task_manager_` tasks: PMU keepalive (5s),
    hub update poll (15s, gated on registered+time-synced), schedule eval (20s), auto-close (2s).
  - `evaluateLocalSchedules()` fires due schedules from a local cache (fed by `SET_SCHEDULE`/
    `REMOVE_SCHEDULE` updates) against `getUnixTimestamp()`, fire-once per epoch-minute, opens valve
    for its duration; the auto-close task closes at the deadline.

## Verification done
Builds clean: `IRRIGATION_AC` (V5, V4) and `IRRIGATION` (V5) regression, SX1262. No warnings/errors.

## Needs bench validation (user flashes)
The always-awake state-machine integration and SSR timing can only be confirmed on hardware:
valve 0/1 on GPIO36/38 open and **hold** while running; node never sleeps; auto-close at deadline;
manual run/stop respond promptly; a stored schedule fires at its time; as a group master, a zone's
one-off run opens this node's valve quickly. `/bramble-flash IRRIGATION_AC` + `bramble-logs`.

## Known limitations / follow-ups
- **Boot schedule enumeration:** the local schedule cache is fed by the update stream only. After a
  reboot, existing PMU-FRAM schedules won't fire until re-pushed by the hub. Follow-up: enumerate via
  `reliable_pmu_->getSchedule(index, ...)` on boot (bounded), or a hub re-sync on registration.
- Local cache holds 32 schedules (indices ≥32 are skipped with a warning).
- Pure-AC only; v3 unsupported (no GPIO36/38); mixed DC+AC not supported.

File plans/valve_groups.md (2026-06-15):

# Valve Groups (Master Valve)

Status: implemented on branch `feature/valve-groups-master-valve`. Full design:
`~/.claude/plans/virtual-sniffing-hanrahan.md`.

## What it does
A **valve group** links N zone valves to one **master valve** (usually on a different node). The
master is a *series* belt-and-suspenders shutoff: water reaches a zone only if both the zone valve
and the master are open. So the master must err **CLOSED** and open only while a specific zone is
actively watering (exact per-zone mirror, closed in the gaps between staggered zones).

## How (API-orchestrated, autonomous nodes)
Nodes sleep between a valve open and its auto-close, so the master can't be coordinated in real time.
Instead the API mirrors each zone watering window onto the **master node as its own schedule**; both
nodes run autonomously from hub-synced RTCs. Only genuinely overlapping zone windows are merged (the
PMU rejects overlapping schedules on one valve). Manual run/stop fan out to the master too.

## Implemented
- **Firmware (PMU):** `MAX_SCHEDULE_ENTRIES` 8 → 100 (`pmu-stm32/Core/Inc/pmu_protocol.h`); FRAM
  `FORMAT_VERSION` 2 → 3 (`persistent_storage.h`) so the auto-derived layout reformats cleanly on
  upgrade. **User must build/flash the PMU.**
- **API index range:** schedule index widened from 0-7 to 0-99 (`models.py`, `app.py`); dashboard
  slot loop too (`IrrigationControl.tsx`).
- **DB (`api/database.py`):** tables `valve_groups`, `valve_group_members`,
  `valve_group_master_slots`; CRUD + `get_group_for_zone_valve` + `list/replace_master_slots`;
  `delete_node` cleanup.
- **Mirror engine (`api/valve_groups.py`, pure):** `compute_master_windows` (per-day overlap merge,
  midnight split, long-window split to fit uint16 duration, distinct-shape day regroup, slot-cap →
  `MasterSlotOverflow`) and `diff_master_slots` (recompute + minimal SET/REMOVE diff, in-place
  shrink/grow, index reuse).
- **Endpoints (`api/app.py`):** `GET/POST /api/valve-groups`, `GET/PUT/DELETE
  /api/valve-groups/<id>`, `POST /api/valve-groups/<id>/resync`; `add_schedule`/`remove_schedule`/
  `run_valve`/`stop_valve` are group-aware (atomic 409 on master slot overflow). Master commands get
  their own `node_commands` audit rows (auto-confirmed by existing event reconcilers).
- **Dashboard:** `components/ValveGroups.tsx` (list/create/edit/delete/resync), nav route, and
  read-only group badges in `IrrigationControl.tsx`.

## Tests
`api/tests/test_valve_groups_engine.py`, `_db.py`, `_api.py` — 34 passing (engine algorithm, DB
layer + uniqueness + cleanup, endpoint wiring). Dashboard `npm run build` + `tsc --noEmit` clean.

## Known limitations / follow-ups
- **TTL expiry** (30 min) can leave the master out of sync → that zone waters with the master closed.
  Mitigated by the manual `/resync`. A periodic reconciler is a recommended v1.1.
- v1 enforces one group per master valve and one group per zone valve.

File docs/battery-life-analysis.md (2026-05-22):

# Battery Life Analysis - Bramble Sensor Node

**Date:** 2026-01-30
**Firmware:** v0.2.16
**Hardware:** SENSOR variant

## Measured Values

| Parameter | Value | Method |
|---|---|---|
| Wake current | 60mA | 6mV over 0.1Ω shunt |
| Sleep current | ~µA | Not measurable on regular multimeter |

## Wake Cycle Timing

### Quiet Wake (no transmission) - ~1.5 seconds

| Phase | Duration |
|---|---|
| Boot → Sensor SM ready | 937ms |
| Sensor read + check backlog | ~500ms |
| **Total** | **~1.5s** |

### Transmit Wake (with radio) - ~5 seconds

| Phase | Duration | Notes |
|---|---|---|
| Boot → Sensor SM ready | 937ms | PMU state restore takes 580ms |
| Sensor read + batch transmit | ~1s | |
| Waiting for heartbeat response | ~2s | Radio latency |
| Batch ACK + receive window | ~1s | 500ms window + processing |
| **Total** | **~5s** | |

## Duty Cycle

- Wake interval: 60 seconds
- Transmit interval: 300 seconds (5 minutes)
- Quiet wakes per cycle: 5
- Transmit wakes per cycle: 1

## Battery Life Calculation

**Battery:** 2 packs of 3×AAA in series
**Capacity:** ~1000mAh

### Per 5-minute cycle

| Activity | Time | Current | Energy |
|---|---|---|---|
| 5 quiet wakes | 7.5s | 60mA | 0.125 mAh |
| 1 transmit wake | 5s | 60mA | 0.083 mAh |
| Sleep | 287s | ~0.01mA | 0.048 mAh |
| **Total** | 300s | | **~0.26 mAh** |

**Average current:** 3.1 mAh/hour

### Estimated Battery Life: ~13 days

## Optimization Opportunities

1. **Increase wake interval** - 60s → 120s or 300s could nearly double or 5x life
2. **Reduce transmit frequency** - batch less often than every 300s
3. **Shorten PMU state restore** - 580ms of 937ms init is waiting for state
4. **Add parallel battery pack** - doubles capacity to ~26 days

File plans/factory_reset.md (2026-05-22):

# Factory Reset Implementation

## Context
The PMU (STM32L010) has FRAM persistent storage (FM24CL16B, 2KB) storing wake interval, schedules, node state blob, and a validity flag. `SystemReset` (command 0x1A) resets the MCU but preserves FRAM. There is no way to clear persisted state — this is needed to fix issues like stale LoRa addresses.

## What exists
- `PersistentStorage::formatStorage()` — private method that zeros FRAM and writes fresh magic/version. Called automatically on first boot.
- `invalidateNodeState()` — clears the valid flag but not the state blob
- `WateringSchedule::clear()` — sets schedule count to 0
- FRAM driver, I2C1, and PersistentStorage are fully wired up in main.cpp

## What's needed
1. ~~**New PMU protocol command** `FactoryReset` (e.g., 0x1B) in `pmu_protocol.h`~~ ✅
2. ~~**Handler** in `pmu_protocol.cpp` that calls `formatStorage()` (make it public or add a `factoryReset()` method on PersistentStorage)~~ ✅
3. ~~**ACK, then reset** — send ACK before formatting, then `NVIC_SystemReset()` after~~ ✅
4. ~~**RP2040 side** — add `factoryReset()` to `ReliablePmuClient` and expose in `SensorPmuManager`~~ ✅
5. **Trigger mechanism** — e.g., hub command via LoRa, or detect a GPIO button hold at boot (TODO)

## Key files
- `pmu-stm32/Core/Inc/pmu_protocol.h` — command enum
- `pmu-stm32/Core/Src/pmu_protocol.cpp` — handler
- `pmu-stm32/Core/Inc/persistent_storage.h` — make formatStorage public
- `src/hal/pmu_protocol.h` — RP2040 command enum
- `src/hal/pmu_reliability.h/.cpp` — reliable client method

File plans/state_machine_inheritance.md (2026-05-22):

# State Machine Inheritance Refactor

## Problem Statement

Currently there are two independent state machines running in `SensorMode`:
1. `BaseStateMachine` (from `ApplicationMode`) - logs as `[StateMachine]`
2. `SensorStateMachine` (in `SensorMode`) - logs as `[SensorSM]`

This causes duplicate log lines like:
```
[+319ms] INFO [StateMachine]: State: INITIALIZING -> AWAITING_TIME
[+400ms] INFO [SensorSM]: State: INITIALIZING -> AWAITING_TIME
```

The design intent was for `SensorStateMachine` to inherit from `BaseStateMachine`, but they're currently separate classes with different paradigms.

## Key Architectural Differences

| Aspect | BaseStateMachine | SensorStateMachine |
|---|---|---|
| **Pattern** | Hardware-polling | Event-driven |
| **States** | 4 (INITIALIZING, AWAITING_TIME, OPERATIONAL, ERROR) | 11 (wake-cycle workflow states) |
| **Update** | `update(BaseHardwareState)` | `reportXyz()` event methods |
| **State derivation** | `deriveState()` virtual method | Mixed: `updateState()` + `transitionTo()` |

## Design Decision

**Option A: True Inheritance** - SensorStateMachine extends BaseStateMachine
- Requires reconciling hardware-polling vs event-driven
- Complex due to different state enums

**Option B: Disable Base in SensorMode** - SensorMode skips BaseStateMachine updates
- Simple fix but doesn't address design intent
- Leaves dead code

**Option C: State Mapping Bridge** (Recommended)
- SensorStateMachine maps its states to BaseState equivalents
- Notifies BaseStateMachine when base-level state changes
- Single source of truth (SensorStateMachine), no duplicate transitions
- ApplicationMode can still query base state if needed

## Recommended Approach: Option C

### Concept

SensorStateMachine internally tracks the equivalent `BaseState` and can report it:

```cpp
class SensorStateMachine {
public:
    // Map sensor state to base state
    BaseState baseState() const {
        switch (state_) {
            case SensorState::INITIALIZING:
                return BaseState::INITIALIZING;
            case SensorState::AWAITING_TIME:
            case SensorState::SYNCING_TIME:
                return BaseState::AWAITING_TIME;
            case SensorState::ERROR:
                return BaseState::ERROR;
            default:  // All operational states
                return BaseState::OPERATIONAL;
        }
    }
};
```

### Changes Required

#### 1. `src/util/sensor_state_machine.h`
- Add `#include "base_state_machine.h"` for `BaseState` enum
- Add `baseState()` method to map SensorState → BaseState
- Add optional `BaseStateCallback` for notifying when base-level state changes

#### 2. `src/util/sensor_state_machine.cpp`
- Implement `baseState()` mapping
- In `transitionTo()`: check if `baseState()` changed, call base callback if set

#### 3. `src/modes/application_mode.h`
- Make `state_machine_` protected (currently private) so subclasses can access
- Or add `baseStateMachine()` accessor

#### 4. `src/modes/application_mode.cpp`
- In `run()`: check if subclass has its own state machine before calling `updateStateMachine()`
- Or: make `updateStateMachine()` virtual so subclasses can override

#### 5. `src/modes/sensor_mode.cpp`
- Option A: Override base state machine updates to be no-op
- Option B: Connect `sensor_state_` to notify `state_machine_` when base state changes
- Remove duplicate state transition logging

## Implementation Plan

### Step 1: Add baseState() mapping to SensorStateMachine
```cpp
// sensor_state_machine.h
#include "base_state_machine.h"

class SensorStateMachine {
public:
    BaseState baseState() const;
    // ...
};

// sensor_state_machine.cpp
BaseState SensorStateMachine::baseState() const {
    switch (state_) {
        case SensorState::INITIALIZING:
            return BaseState::INITIALIZING;
        case SensorState::AWAITING_TIME:
        case SensorState::SYNCING_TIME:
            return BaseState::AWAITING_TIME;
        case SensorState::ERROR:
            return BaseState::ERROR;
        default:
            return BaseState::OPERATIONAL;
    }
}
```

### Step 2: Prevent duplicate BaseStateMachine transitions in SensorMode

In `ApplicationMode::run()`, add a virtual method that subclasses can override:

```cpp
// application_mode.h
protected:
    virtual bool usesCustomStateMachine() const { return false; }

// application_mode.cpp - in run()
if (!usesCustomStateMachine()) {
    state_machine_.markInitialized();
    updateStateMachine();
}

// sensor_mode.h
protected:
    bool usesCustomStateMachine() const override { return true; }
```

### Step 3: (Optional) Bridge callback for base state changes

If ApplicationMode needs to react to base-level state changes from sensor:

```cpp
// In SensorMode::onStart()
sensor_state_.setBaseStateCallback([this](BaseState base) {
    // Could update ApplicationMode's state_machine_ if needed
    // Or just use for logging coordination
});
```

## Files to Modify

1. `src/util/sensor_state_machine.h` - Add baseState() method
2. `src/util/sensor_state_machine.cpp` - Implement baseState()
3. `src/modes/application_mode.h` - Add usesCustomStateMachine() virtual
4. `src/modes/application_mode.cpp` - Check before base state machine init
5. `src/modes/sensor_mode.h` - Override usesCustomStateMachine()

## Verification

1. Build: `/bramble-build SENSOR`
2. Flash and observe logs - should see only `[SensorSM]` state transitions, not duplicate `[StateMachine]` lines
3. Verify wake cycle works correctly:
   - Boot → INITIALIZING → AWAITING_TIME (after PMU state restored)
   - Time sync → TIME_SYNCED
   - Sensor read → READING_SENSOR → CHECKING_BACKLOG
   - TX if needed → TRANSMITTING → READY_FOR_SLEEP
4. Verify `sensor_state_.baseState()` returns correct base state at each point

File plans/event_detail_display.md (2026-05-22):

# Event detail display

## Goal

Make `Recent Events` in the dashboard show useful detail per event:

1. **Sub-minute timestamps** — 11 events in the screenshot all read `19:03`. We have
   second-precision data; we're just rendering `HH:mm`.
2. **Watering duration** — for a VALVE_OPEN / VALVE_TIMER_SET, surface how long the
   watering ran (or is running). Today there's no way to tell `15min` schedule from
   `5min Run` from the event log alone.
3. **Which valve** — events say "Valve Open" with no valve ID. We have the ID, we're
   not displaying it.

## What we have on the wire today

`src/util/event_record.h`:

```cpp
struct EventRecord {
    uint16_t uptime_offset;  // seconds since time reference
    uint8_t  event_type;     // EventType enum
    uint8_t  severity;       // 0/1/2
    uint16_t detail;         // event-specific
};  // 6 bytes packed
```

Hub serial bridge (`api/serial_interface.py:494-502`) packs `severity` + `detail`
into `data_hex` like `"000003"` and stores it in the `node_events` row. The
dashboard receives `NodeEvent { device_id, timestamp, event_code, data_hex }`
(`dashboard/src/types/index.ts:233`) but **never reads `data_hex`**.

For irrigation events the `detail` field currently carries:

| EventType | detail meaning | source |
|---|---|---|
| VALVE_OPEN | valve_id | `irrigation_mode.cpp:448, 358` |
| VALVE_CLOSE | valve_id | `irrigation_mode.cpp:453` |
| VALVE_TIMER_SET | valve_id | `irrigation_mode.cpp:237` |
| VALVE_TIMER_CLOSE | valve_id | `irrigation_mode.cpp:345` |
| SCHEDULE_APPLIED  | schedule index | `irrigation_mode.cpp:552` |
| SCHEDULE_REMOVED  | schedule index | `irrigation_mode.cpp:579` |
| SCHEDULE_FAILED | schedule index | `irrigation_mode.cpp:558, 583` |

**Duration is not on the wire.** It has to be added.

Timestamps already have second precision end-to-end — only the render is truncated
(`dashboard/src/components/RecentEvents.tsx:214`, `:487-488`).

## Approach

Three independent changes, do them in order — each is shippable on its own.

### 1. Render `HH:mm:ss` instead of `HH:mm`

Trivial. Two `format(date, 'HH:mm')` call sites in `RecentEvents.tsx`:
- `:214` — single event row (`CopyableTimestamp`)
- `:487-488` — collapsed wake/sleep range label

Risk: the row gets a few pixels wider. Mono font already; should fit.

### 2. Render detail in the event label

Decode `data_hex` (already on `NodeEvent`) and append context:

- `VALVE_OPEN | VALVE_CLOSE | VALVE_TIMER_SET | VALVE_TIMER_CLOSE` → `"Valve N"` suffix (e.g. `"Valve Open · Valve 1"`)
- `SCHEDULE_APPLIED | SCHEDULE_REMOVED | SCHEDULE_FAILED` → `"#<index>"` suffix

Helper in `dashboard/src/types/index.ts` (next to `getEventName`):

```ts
export function getEventDetail(code: number, dataHex: string): string | null {
  if (!dataHex || dataHex.length < 6) return null;
  const detail = parseInt(dataHex.slice(2, 6), 16);
  switch (code) {
    case EventType.VALVE_OPEN:
    case EventType.VALVE_CLOSE:
    case EventType.VALVE_TIMER_SET:
    case EventType.VALVE_TIMER_CLOSE:
      return `Valve ${detail + 1}`;            // 1-indexed for display
    case EventType.SCHEDULE_APPLIED:
    case EventType.SCHEDULE_REMOVED:
    case EventType.SCHEDULE_FAILED:
      return `#${detail}`;
    default:
      return null;
  }
}
```

Render site is the event row span in `RecentEvents.tsx:564` and `:526` (collapsed
expansion). Append the detail with a subtle separator if non-null.

Decision needed: 0- or 1-indexed? Schedules list in screenshot already shows
`Valve 1 / Valve 2` (1-indexed) so match that.

### 3. Add duration to watering events

Two sub-options. Pick one.

**Option A — Pair on the dashboard.** Walk the event list; for each
`VALVE_OPEN(valve=X)` find the next `VALVE_TIMER_CLOSE(valve=X)` or
`VALVE_CLOSE(valve=X)` and compute `close.timestamp - open.timestamp`. Render
as `"Valve Open · Valve 1 · 60s"`.

- Pro: no firmware/protocol change. Works for events already in DB.
- Con: ambiguous if pairs span page boundaries (loadMore). Ambiguous if events arrive out of order or get dropped.
- Edge cases: open with no matching close → `"ongoing"`; close with no open → leave bare.

**Option B — Encode duration on the wire.** Repurpose the 16-bit `detail` to pack
both valve ID and duration. 4 bits valve (16 valves max — we use 4), 12 bits
duration in 4-second units = ~68 minutes max. For schedules that go longer,
saturate. Or use 16 bits for duration on `VALVE_TIMER_SET` only (drop valve ID
from that event — duration is the interesting bit, valve ID is implicit from the
preceding `VALVE_OPEN`).

- Pro: exact, no pairing logic.
- Con: protocol change. Need to update node firmware (`irrigation_mode.cpp:237, 232-239`), serial bridge (`api/serial_interface.py:494-502`), regenerate types.

**Recommendation: A first.** Most watering events come in pairs within one TX batch
(open → sleep enter → ... → wake → valve timer close, all in one wake cycle's
event log). Dashboard pairing covers 90% of real use. Revisit B if pairing
quality is poor in practice.

For Option A, the pairing function lives in `RecentEvents.tsx` next to
`collapseWakeCycles`. Pseudo:

```ts
function annotateDurations(events: NodeEvent[]): Map<number, number> {
  // events assumed sorted desc by timestamp (as the API returns them)
  const durationByOpenTs = new Map<number, number>();
  const openByValve = new Map<number, NodeEvent>();
  // walk oldest→newest, so reverse iterate
  for (let i = events.length - 1; i >= 0; i--) {
    const e = events[i];
    const valveId = parseInt(e.data_hex.slice(2, 6), 16);
    if (e.event_code === EventType.VALVE_OPEN) {
      openByValve.set(valveId, e);
    } else if (
      e.event_code === EventType.VALVE_CLOSE ||
      e.event_code === EventType.VALVE_TIMER_CLOSE
    ) {
      const open = openByValve.get(valveId);
      if (open) {
        durationByOpenTs.set(open.timestamp, e.timestamp - open.timestamp);
        openByValve.delete(valveId);
      }
    }
  }
  return durationByOpenTs;
}
```

Render: if `durationByOpenTs.has(event.timestamp)` and `event.event_code === VALVE_OPEN`,
append `· ${formatDuration(duration)}` (e.g. `60s`, `5m`, `15m 30s`).

## Open questions for the user

1. **1-indexed valves in display?** (Schedules already show `Valve 1` / `Valve 2`.)
2. **Where to put detail in the row** — same line (`"Valve Open · Valve 1 · 60s"`)
   or a second line under the event name? Single-line is more scannable; second
   line gives more breathing room when many events stack.
3. **Pairing only (Option A) or wire-format duration (Option B)?** Auto-mode-friendly
   if A; B requires firmware reflash on all irrigation nodes.

## File touch list

- `dashboard/src/types/index.ts` — add `getEventDetail`, `formatDuration` helpers
- `dashboard/src/components/RecentEvents.tsx` — sub-minute timestamps + detail + duration

If Option B is chosen later:
- `src/modes/irrigation_mode.cpp` — pack duration into detail
- `api/serial_interface.py` — unchanged (still ships `severity:detail`)
- `dashboard/src/types/index.ts` — decode new layout

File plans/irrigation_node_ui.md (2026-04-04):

# Irrigation Node Detail Page - Design Plan

## Context

The irrigation node boots, registers with the hub, and supports:
- **2 DC latching solenoid valves** (via H-bridge + valve indexer)
- **PMU-managed schedules** (up to 8 entries, stored in STM32 FRAM)
- **Update pull system**: hub queues updates (schedules, wake interval, datetime), node pulls on wake
- **Actuator commands**: real-time valve on/off via `MSG_TYPE_ACTUATOR_CMD`

### Existing API Endpoints
| Endpoint | Method | Purpose |
|---|---|---|
| `/api/nodes/<device_id>/schedules` | POST | Add/update a schedule entry |
| `/api/nodes/<device_id>/schedules/<index>` | DELETE | Remove a schedule entry |
| `/api/nodes/<device_id>/wake-interval` | POST | Set periodic wake interval |
| `/api/nodes/<int:address>/curtain` | POST | Curtain control (reference pattern) |

### Missing API Endpoints
| Endpoint | Method | Purpose |
|---|---|---|
| `/api/nodes/<device_id>/valve` | POST | Manual valve on/off (best effort) |
| `/api/nodes/<device_id>/schedules` | GET | List current schedules (need to store server-side) |

### Existing UI Patterns
- `CurtainControl.tsx` — actuator control card with action buttons + event history
- `NodeDetail.tsx` — 3-column layout: left sidebar (stats, info, status, advanced), right 2-col (actuator-specific + sensor data)
- Node type detection via `NodeType.IRRIGATION` already in types

## Design

### Page Layout (Irrigation Node Detail)

Same structure as existing NodeDetail, but the right 2-col area shows **IrrigationControl** instead of sensor charts when `node.type === NodeType.IRRIGATION`.

```
┌─────────────────────────────────────────────────┐
│ ← Back to nodes                                 │
│ Node Name                          [Refresh]    │
│ ● Online  IRRIGATION                            │
├──────────────┬──────────────────────────────────┤
│ Node Info    │  ┌─ Run Once ───────────────────┐ │
│ (name/zone)  │  │ Valve 1  [5m][15m][30m][__] │ │
│              │  │                       [Run] │ │
│ Node Status  │  │ Valve 2  [5m][15m][30m][__] │ │
│ (battery,    │  │                       [Run] │ │
│  signal,     │  │ ⚠ Node must be awake        │ │
│              │  └─────────────────────────────┘ │
│  uptime)     │                                  │
│              │  ┌─ Schedules ─────────────────┐ │
│ Advanced     │  │ ┌──────────────────────────┐│ │
│ (reboot,     │  │ │ Valve 1 · 06:00 · 15min ││ │
│  delete)     │  │ │ Mon-Fri      [Edit][Del] ││ │
│              │  │ ├──────────────────────────┤│ │
│              │  │ │ Valve 2 · 18:00 · 30min ││ │
│              │  │ │ Every day    [Edit][Del] ││ │
│              │  │ └──────────────────────────┘│ │
│              │  │                              │ │
│              │  │ [+ Add Schedule]             │ │
│              │  └─────────────────────────────┘ │
│              │                                  │
│              │  ┌─ Recent Events ─────────────┐ │
│              │  │ Valve 1 opened    Apr 4 6:00│ │
│              │  │ Valve 1 closed    Apr 4 6:15│ │
│              │  └─────────────────────────────┘ │
└──────────────┴──────────────────────────────────┘
```

### Component: `IrrigationControl`

**Props**: `{ address: number, deviceId: string }`

Three sections, each in its own card:

#### 1. Run Once (Manual Watering)
- Two rows, one per valve
- Each row: valve label, duration picker (preset buttons: 5m, 15m, 30m, or custom minutes), [Run] button
- When triggered, sends a "run once" command: opens the valve, auto-closes after the specified duration
- Info note: "Best-effort — the node must be awake to receive the command"
- No raw on/off — eliminates the risk of forgetting a valve open
- API: `POST /api/nodes/<device_id>/valve` with `{ valve: 0|1, duration_seconds: 900 }`
- The auto-off is handled by the PMU scheduled wake: hub queues a SET_SCHEDULE with a one-shot entry (or the firmware handles a timed valve command directly)

#### 2. Schedules
- List of active schedules, fetched from server-side storage
- Each entry shows: valve, time (HH:MM), duration (human-readable), days of week, edit/delete buttons
- "Add Schedule" button opens an **inline form** (not a modal — keeps it simple)
- Schedule form fields:
  - Valve: dropdown (Valve 1 / Valve 2)
  - Time: hour + minute inputs
  - Duration: number input in minutes (converted to seconds for API)
  - Days: 7 toggle buttons (M T W T F S S)
- API: existing `POST /schedules` and `DELETE /schedules/<index>`
- **Server-side schedule storage**: schedules are fire-and-forget (queued for node delivery). We need a `GET /schedules` endpoint that returns the *intended* schedule state. Store schedule entries in the database when POST is called, remove on DELETE.

#### 3. Recent Events
- Same pattern as CurtainControl event history
- Scrollable table with event name + timestamp
- Uses existing `GET /api/nodes/<device_id>/events`

### New Event Codes
Add to `EVENT_CODE_NAMES` in types:
```
0x0200: 'Valve 1 Opened'
0x0201: 'Valve 1 Closed'
0x0202: 'Valve 2 Opened'
0x0203: 'Valve 2 Closed'
```

### API Changes Needed

#### 1. `POST /api/nodes/<device_id>/valve` (new)
Send a "run once" valve command with auto-off after specified duration.

```python
@app.route('/api/nodes/<int:device_id>/valve', methods=['POST'])
def run_valve_once(device_id):
    # body: { "valve": 0, "duration_seconds": 900 }
    # Implementation options:
    # a) Queue a one-shot PMU schedule entry (hub sets schedule, PMU wakes node and runs it)
    # b) Send actuator CMD_TURN_ON + queue a delayed CMD_TURN_OFF (fragile if node sleeps)
    # Recommend (a) — PMU handles the timing reliably even through sleep cycles
```

#### 2. `GET /api/nodes/<device_id>/schedules` (new)
Return the intended schedule state from local DB. Needed because schedules are queued asynchronously — we can't query the node directly.

#### 3. Schedule persistence table (new)
Store schedule entries when POST'd, remove on DELETE. Schema:
```sql
CREATE TABLE irrigation_schedules (
    device_id TEXT NOT NULL,
    index INTEGER NOT NULL,
    hour INTEGER NOT NULL,
    minute INTEGER NOT NULL,
    duration INTEGER NOT NULL,
    days INTEGER NOT NULL,
    valve INTEGER NOT NULL,
    created_at INTEGER NOT NULL,
    PRIMARY KEY (device_id, index)
);
```

### Integration into NodeDetail.tsx

In the right 2-col area, add:
```tsx
{node.type === NodeType.IRRIGATION && (
  <IrrigationControl address={node.address} deviceId={node.device_id} />
)}
```

Same pattern as the existing greenhouse/curtain conditional.

## Implementation Order

1. **API**: Add valve control endpoint, schedule persistence table, GET schedules endpoint
2. **Dashboard types**: Add irrigation event codes, schedule types, API client methods
3. **IrrigationControl component**: Valve control card, schedule list/form, event history
4. **NodeDetail integration**: Wire up IrrigationControl for IRRIGATION nodes
5. **Build & test**: `npx tsc --noEmit` for type checking

## Open Questions

- Should schedules show a "pending delivery" status? (The node may not have received the schedule yet if it's sleeping.) **Recommendation**: yes, show a subtle "queued" badge if the schedule was just created and the node hasn't pulled updates yet.
- **Run-once delivery**: Queue a one-shot PMU schedule entry. The PMU will wake the node at the right time and run the valve for the specified duration. Works even if the node is currently asleep.
- **Stop button**: Show a "Stop" button while a run-once is active. Since the node is necessarily awake during a valve run, the stop command (CMD_TURN_OFF) should arrive quickly.

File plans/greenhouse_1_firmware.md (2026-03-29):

# Increment 1: Greenhouse Firmware Core

## Goal
Build and flash a GREENHOUSE variant that initializes the curtain motor controller, registers with the hub, and handles actuator commands over LoRa.

## New Protocol Constants
**File**: `src/lora/message.h`
- Add `ACTUATOR_CURTAIN = 0x04` to `ActuatorType`
- Add `CMD_STOP = 0x04`, `CMD_CALIBRATE = 0x05` to `ActuatorCommand`

## New Files

### `src/hal/curtain_controller.h` / `.cpp`
2-GPIO non-blocking motor driver.

**States**: `UNKNOWN, OPEN, CLOSED, OPENING, CLOSING, STOPPED, CALIBRATING, ERROR`

**Interface**:
- `initialize(open_pin, close_pin)` — configure GPIOs as output, both LOW
- `open()` — assert close LOW, set open HIGH, record start time, state→OPENING
- `close()` — assert open LOW, set close HIGH, record start time, state→CLOSING
- `stop()` — both LOW, update estimated_position from elapsed/travel_time, state→STOPPED
- `update()` — called every loop; if motor running: check elapsed vs travel_time (stop if done), check safety timeout (stop + ERROR if exceeded)
- `getState()`, `getEstimatedPosition()`, `getTravelTime()`, `setTravelTime()`

**Safety**: `max_motor_run_ms_` = 180000 (3 min). Motor always stops if exceeded.

**Pin assignments**: Define `PIN_CURTAIN_OPEN` and `PIN_CURTAIN_CLOSE` in `src/board/bramble_v4_pins.h`. Reuse two existing motor GPIOs (PIN_MOTOR_HI_1, PIN_MOTOR_HI_2) or pick available GPIOs — exact pins TBD with user based on wiring.

### `src/modes/greenhouse_mode.h` / `.cpp`
Extends `ApplicationMode`. Pattern follows `irrigation_mode`.

- `shouldSleep()` → `false`
- `onStart()` → init curtain controller, init PMU for RTC, set LED pattern (green pulse), send heartbeat
- `onLoop()` → `curtain_controller_.update()`
- `onActuatorCommand()` → dispatch ACTUATOR_CURTAIN commands to curtain controller
- `onHeartbeatResponse()` → sync RTC via PMU (reuse irrigation pattern)

### `src/util/greenhouse_state_machine.h` / `.cpp`
States: INITIALIZING → AWAITING_TIME → IDLE ↔ CURTAIN_MOVING / ERROR
Follow `IrrigationStateMachine` pattern.

## Modified Files

### `CMakeLists.txt`
- Add GREENHOUSE to `set_property(CACHE HARDWARE_VARIANT PROPERTY STRINGS ...)`
- Add build block for `bramble_greenhouse` executable with sources: `greenhouse_mode.cpp`, `curtain_controller.cpp`, `greenhouse_state_machine.cpp`, `${COMMON_SOURCES}`
- Define `HARDWARE_GREENHOUSE=1`, `DEFAULT_IS_HUB=0`

### `main.cpp`
- Add `#ifdef HARDWARE_GREENHOUSE` include for `modes/greenhouse_mode.h`
- Add to `getVariantInfo()`: `{NODE_TYPE_ACTUATOR, CAP_VALVE_CONTROL, "Greenhouse Node"}`
- Add variant log line
- Add mode instantiation block (no PMU sleep signaling)

## Verification
1. `cmake -B build -DHARDWARE_VARIANT=GREENHOUSE` → builds successfully
2. `cmake -B build -DHARDWARE_VARIANT=ALL` → still builds all variants
3. Flash to V4 board → serial shows "GREENHOUSE mode", registers with hub
4. Heartbeat shows correct node type and capabilities

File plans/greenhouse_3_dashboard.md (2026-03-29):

# Increment 3: Dashboard Controls

## Goal
Add API endpoint and React UI for open/close/stop curtain control. After this increment, users can control the greenhouse curtain from their browser.

## API Changes

### `api/command_queue.py`
- Add `queue_send_actuator(node_address, actuator_type, command, param=0)`:
  - Sends `SEND_ACTUATOR <addr> <type> <cmd> <param>` via hub serial

### `api/app.py`
- Add `POST /api/nodes/<address>/curtain` endpoint:
  - Body: `{"action": "open" | "close" | "stop"}`
  - Maps actions to actuator commands (ACTUATOR_CURTAIN=4, CMD_TURN_ON=1, CMD_TURN_OFF=0, CMD_STOP=4)
  - Calls `queue_send_actuator()`, returns 202 with task_id

## Dashboard Changes

### `dashboard/src/api/client.ts`
- Add `controlCurtain(address, action)` function → POST to `/api/nodes/<address>/curtain`

### `dashboard/src/components/CurtainControl.tsx` (new)
- Three buttons: Open (green), Stop (amber), Close (red)
- Status display: current curtain state, estimated position
- Rendered as a card within NodeDetail for greenhouse-type nodes

### `dashboard/src/components/NodeDetail.tsx`
- Import and render `<CurtainControl>` when node type is "GREENHOUSE"

### `dashboard/src/types/index.ts` (if node types are defined here)
- Add GREENHOUSE to node type constants

## Verification
1. Start API server and dashboard dev server
2. Greenhouse node visible in node list with correct type
3. NodeDetail page shows curtain control card with Open/Stop/Close buttons
4. Clicking buttons sends correct API calls, hub forwards LoRa commands
5. Curtain motor responds to each command

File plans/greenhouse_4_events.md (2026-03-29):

# Increment 4: Event Recording

## Goal
Record curtain open/close/stop events so there's operational visibility into what the greenhouse controller has done.

## Firmware Changes

### `src/lora/message.h`
- Add `SENSOR_EVENT = 0x10` to `SensorType` enum

### `src/modes/greenhouse_mode.cpp`
- After each curtain action (open/close/stop), send a `MSG_TYPE_SENSOR_DATA` message to hub with:
  - `sensor_type = SENSOR_EVENT`
  - Payload: `{event_type (1 byte), timestamp (4 bytes), elapsed_ms (4 bytes)}`
- Use BEST_EFFORT delivery (events are informational, not critical)

## API Changes

### `api/database.py`
- Add `actuator_events` table:
  - `device_id BIGINT, timestamp INTEGER, event_type VARCHAR, details VARCHAR, received_at INTEGER`
- Add `insert_actuator_event()` and `get_actuator_events(device_id, start, end)` methods

### `api/serial_interface.py`
- Parse incoming SENSOR_EVENT data from hub serial output
- Insert into `actuator_events` table

### `api/app.py`
- Add `GET /api/nodes/<device_id>/events` endpoint
  - Query params: `start`, `end` (time range)
  - Returns list of events with timestamp, type, details

## Dashboard Changes

### `dashboard/src/components/CurtainControl.tsx`
- Add event history section below the control buttons
- Fetch and display recent events (last 20) with timestamps

### `dashboard/src/api/client.ts`
- Add `getNodeEvents(deviceId, start?, end?)` function

## Verification
1. Open/close/stop curtain from dashboard
2. Events appear in `GET /api/nodes/<device_id>/events` response
3. Event history visible in dashboard CurtainControl component
4. Events persist across node/API restarts

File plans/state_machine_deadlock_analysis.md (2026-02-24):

# Sensor State Machine Deadlock Analysis

## Summary

Analysis of every state in `SensorStateMachine` to verify that all states have
valid exit transitions for all permutations of input conditions. **Seven issues
found**, two of which are confirmed deadlocks that will halt the device.

---

## State-by-State Analysis

### 1. INITIALIZING

**Entry:** Default state on boot.

**Exit paths:**
- `markInitialized()` → REGISTERING (via PMU wake callback or `!pmu_ok` fallback)
- `markError()` → ERROR

**Verdict: OK** — PMU has a 1000ms wake notification timeout that guarantees the
callback fires. The `!pmu_ok` fallback calls `markInitialized()` directly.

---

### 2. REGISTERING

**Entry:** From INITIALIZING via `markInitialized()`.

**Exit paths:**
- Already registered → `reportRegistrationComplete()` → AWAITING_TIME (immediate)
- Registration sent, response received → callback → `reportRegistrationComplete()` → AWAITING_TIME
- Registration sent, timeout (5000ms) → `reportRegistrationTimeout()` → READY_FOR_SLEEP
- Registration send failed (seq == 0) → `reportRegistrationTimeout()` → READY_FOR_SLEEP

**Verdict: OK** — All paths have exit transitions. Timeout guarantees escape.

---

### 3. AWAITING_TIME

**Entry:** From REGISTERING via `reportRegistrationComplete()`, or from
READY_FOR_SLEEP via `reportWakeFromSleep()`.

**Exit paths (via `requestTimeSync()` posted in onStateChange):**
- PMU available, valid time, time to transmit → `reportHeartbeatSent()` → SYNCING_TIME
- PMU available, valid time, NOT time to transmit → `reportTimeSyncComplete()` → TIME_SYNCED
- PMU available, time NOT valid → `reportHeartbeatSent()` → SYNCING_TIME
- PMU NOT available → `reportHeartbeatSent()` → SYNCING_TIME

**BUG — `rtc_set_datetime()` failure:** If PMU has valid time but
`rtc_set_datetime()` fails (`sensor_mode.cpp:838`), the code logs an error and
falls through the callback with **no state transition**. No timeout is set for
AWAITING_TIME. The state machine halts here permanently.

```cpp
// sensor_mode.cpp:838-840
} else {
    logger.error("Failed to set RTC from PMU time");
    // *** NO STATE TRANSITION — STUCK IN AWAITING_TIME ***
}
```

**Verdict: DEADLOCK** — Missing transition on `rtc_set_datetime()` failure.

**Fix:** Fall back to hub sync (send heartbeat) when `rtc_set_datetime()` fails:
```cpp
} else {
    logger.error("Failed to set RTC from PMU time - falling back to hub sync");
    heartbeat_client_->send();
    sensor_state_.expectResponse();
    sensor_state_.reportHeartbeatSent();
}
```

---

### 4. SYNCING_TIME

**Entry:** From AWAITING_TIME via `reportHeartbeatSent()`.

**Exit paths:**
- Hub response received → heartbeat response callback → `reportTimeSyncComplete()` → TIME_SYNCED
- Heartbeat delivery failed + RTC running → `reportTimeSyncComplete()` → TIME_SYNCED
- Heartbeat delivery failed + no RTC → `reportSyncTimeout()` → READY_FOR_SLEEP
- Timeout (5000ms) + RTC running → `reportTimeSyncComplete()` → TIME_SYNCED
- Timeout (5000ms) + no RTC → `reportSyncTimeout()` → READY_FOR_SLEEP

**Verdict: OK** — The 5000ms timeout guarantees an exit in all conditions.

---

### 5. TIME_SYNCED

**Entry:** From SYNCING_TIME or AWAITING_TIME via `reportTimeSyncComplete()`.

**Exit paths (via `tryInitSensor()` posted in onStateChange):**
- Sensor already initialized → `reportSensorInitSuccess()` → READING_SENSOR
- Sensor init succeeds → `reportSensorInitSuccess()` → READING_SENSOR
- Sensor init fails → `reportSensorInitFailure()` → DEGRADED_NO_SENSOR
- `sensor_` is null → `tryInitSensor()` returns false, **no state transition**

**Edge case:** If `sensor_` is null, `tryInitSensor()` at line 765 returns
`false` without calling any state machine event. The state machine stays in
TIME_SYNCED. `sensor_` is created in `onStart()` so this is very unlikely, but
the code path is not robust.

```cpp
// sensor_mode.cpp:765-767
if (!sensor_) {
    return false;  // *** NO STATE TRANSITION ***
}
```

**Verdict: MINOR RISK** — Unlikely (sensor_ always created in onStart), but
undefended. Should call `reportSensorInitFailure()` when sensor_ is null.

**Fix:**
```cpp
if (!sensor_) {
    sensor_state_.reportSensorInitFailure();
    return false;
}
```

**Design note — lazy init retry for transient failures:** Sensor initialization
failures are not always permanent. I²C bus glitches, power-on settling delays,
and similar transient conditions can cause a single init attempt to fail even
when the hardware is functioning. Rather than sending the state machine
permanently to `DEGRADED_NO_SENSOR` on first failure, consider a lazy retry
approach: on init failure, transition to `READY_FOR_SLEEP` instead. On the next
Periodic wake the full cycle restarts (AWAITING_TIME → TIME_SYNCED → sensor
init), giving the sensor a fresh opportunity to initialize. A retry counter can
cap the number of attempts before escalating to DEGRADED_NO_SENSOR, so a truly
absent sensor is still reported correctly after N failed cycles.

**Why the retry works with existing flag logic:** `reportSensorInitFailure()`
already sets `sensor_initialized_ = false` (line 91 of `sensor_state_machine.cpp`).
Since `hasSensor()` returns `sensor_initialized_`, `tryInitSensor()` will not take
the "already working" shortcut on the retry cycle — it will call `sensor_->init()`
again. No changes to flag handling in `tryInitSensor()` are needed beyond adding
the DEGRADED_NO_SENSOR exit transition.

**Retry counter placement:** For a per-wake-cycle retry counter,
`reportWakeFromSleep()` should reset `sensor_init_attempted_` alongside
`expected_responses_`. Without that reset, the counter state must be maintained
externally in `SensorMode`. Either approach works; resetting inside the state
machine keeps all retry bookkeeping in one place.

---

### 6. READING_SENSOR

**Entry:** From TIME_SYNCED via `reportSensorInitSuccess()` → `updateState()`.

**Exit paths (from onStateChange task):**
```cpp
self->readAndStoreSensorData(time);
self->sensor_state_.reportReadComplete();  // Always called
```

`reportReadComplete()` → CHECKING_BACKLOG. The call to `reportReadComplete()` is
unconditional — it always runs regardless of whether `readAndStoreSensorData()`
succeeds or fails internally.

**Verdict: OK** — `reportReadComplete()` is always called.

---

### 7. CHECKING_BACKLOG

**Entry:** From READING_SENSOR via `reportReadComplete()`.

**Exit paths (from onStateChange task):**
```cpp
bool needsTx = self->checkNeedsTransmission();
self->sensor_state_.reportCheckComplete(needsTx);
```

- `reportCheckComplete(true)` → TRANSMITTING
- `reportCheckComplete(false)` + `hasExpectedResponses()` → LISTENING
- `reportCheckComplete(false)` + no responses → READY_FOR_SLEEP

**Verdict: OK** — `reportCheckComplete()` is always called; all branches have
transitions.

---

### 8. TRANSMITTING

**Entry:** From CHECKING_BACKLOG via `reportCheckComplete(true)`.

**Exit paths:**
- `transmitBacklog()` callback → `reportTransmitComplete()` → LISTENING or READY_FOR_SLEEP
- `transmitCurrentReading()` callback → `reportTransmitComplete()` → LISTENING or READY_FOR_SLEEP
- Various error paths (null flash, read failure, null reading) → `reportTransmitComplete()`

**Risk:** All exit paths depend on the `BatchTransmitter` callback eventually
firing. The reliable messenger has retry limits and timeouts, so the callback
_should_ always fire. However, there is **no safety timeout** on the
TRANSMITTING state itself. If the messenger gets into an unexpected state (e.g.,
task queue starvation, SPI bus lockup), the callback may never fire and the state
machine halts.

**Verdict: MEDIUM RISK** — No safety timeout. This, combined with the existing
per-state timeouts for REGISTERING and SYNCING_TIME, suggests a generic
per-state watchdog mechanism (see §Generic State Watchdog below).

---

### 9. LISTENING

**Entry:** From TRANSMITTING or CHECKING_BACKLOG.

**Exit paths:**
- 500ms timeout fires → `reportListenComplete()` → READY_FOR_SLEEP

**Verdict: OK** — Timeout guarantees an exit.

---

### 10. READY_FOR_SLEEP

**Entry:** From REGISTERING, SYNCING_TIME, CHECKING_BACKLOG, TRANSMITTING, or
LISTENING.

**Exit paths:**
- PMU periodic wake → `reportWakeFromSleep()` → AWAITING_TIME
- PMU scheduled wake → **logs warning only, no transition**
- PMU external wake → **logs info only, no transition**
- PMU unavailable → `signalReadyForSleep()` returns silently, **no wake will come**

```cpp
// sensor_mode.cpp:137-150 (PMU wake callback)
switch (reason) {
    case PMU::WakeReason::Periodic:
        sensor_state_.reportWakeFromSleep();  // ✓ transitions out
        break;
    case PMU::WakeReason::Scheduled:
        pmu_logger.warn("Unexpected scheduled wake in sensor mode");
        break;  // *** NO TRANSITION ***
    case PMU::WakeReason::External:
        pmu_logger.info("External wake trigger");
        break;  // *** NO TRANSITION ***
}
```

**Verdict: MEDIUM RISK** — Scheduled/External wakes are dead ends. And if PMU is
unavailable, the device is stuck in READY_FOR_SLEEP forever with no recovery.

**Fix:** Treat all wake reasons as valid:
```cpp
switch (reason) {
    case PMU::WakeReason::Periodic:
    case PMU::WakeReason::External:
        sensor_state_.reportWakeFromSleep();
        break;
    case PMU::WakeReason::Scheduled:
        pmu_logger.warn("Unexpected scheduled wake in sensor mode");
        sensor_state_.reportWakeFromSleep();
        break;
}
```

For the no-PMU case, use `postDelayed` to schedule the next wake cycle directly
(see §Generic State Watchdog — READY_FOR_SLEEP software timer).

---

### 11. DEGRADED_NO_SENSOR

**Entry:** From TIME_SYNCED via `reportSensorInitFailure()` → `updateState()`.

**Exit paths (from onStateChange):**
```cpp
case SensorState::DEGRADED_NO_SENSOR:
    // ...
    bool needsTx = self->checkNeedsTransmission();
    self->sensor_state_.reportCheckComplete(needsTx);  // *** REJECTED ***
    break;
```

The state machine's `reportCheckComplete()` has a guard:
```cpp
void SensorStateMachine::reportCheckComplete(bool needsTransmit)
{
    if (state_ != SensorState::CHECKING_BACKLOG) {  // state is DEGRADED_NO_SENSOR!
        logger.warn("reportCheckComplete() called in unexpected state: %s", ...);
        return;  // *** REJECTED — NO TRANSITION ***
    }
```

The call is rejected because the current state is DEGRADED_NO_SENSOR, not
CHECKING_BACKLOG. **The state machine has no exit from DEGRADED_NO_SENSOR.** The
device halts permanently in this state.

**Verdict: CONFIRMED DEADLOCK** — This is the most critical bug. Any sensor
initialization failure permanently halts the wake cycle.

**Fix — transition to READY_FOR_SLEEP and retry on next wake cycle:**

The correct exit from DEGRADED_NO_SENSOR is `READY_FOR_SLEEP`, not
`CHECKING_BACKLOG`. This allows the device to sleep and then repeat the full
wake cycle on the next Periodic PMU event, giving the sensor another
initialization attempt. This implements the lazy-retry strategy described in the
TIME_SYNCED section above — sensor failures are often transient, and sleeping
then retrying is safer than either halting or routing through unrelated backlog
logic.

Add a dedicated `reportSensorRetry()` transition (or reuse an existing one) that
exits DEGRADED_NO_SENSOR directly to READY_FOR_SLEEP:

```cpp
// In SensorStateMachine, add a new event:
void SensorStateMachine::reportSensorRetry()
{
    if (state_ != SensorState::DEGRADED_NO_SENSOR) {
        logger.warn("reportSensorRetry() called in unexpected state: %s", ...);
        return;
    }
    transitionTo(SensorState::READY_FOR_SLEEP);
}
```

Then call it from `onStateChange` for DEGRADED_NO_SENSOR:
```cpp
case SensorState::DEGRADED_NO_SENSOR:
    led_pattern_ = std::make_unique<ShortBlinkPattern>(led_, 255, 165, 0);
    // Sleep and retry init on next wake
    sensor_state_.reportSensorRetry();
    break;
```

A retry counter should guard against infinite loops on permanently absent
hardware — after N failed wake cycles the machine may escalate to ERROR or stop
retrying.

---

### 12. ERROR

**Entry:** From any state via `markError()`.

**Exit paths:** None by design — only recoverable via hardware reset/watchdog.

**Verdict: OK** — Terminal state, intentional.

---

---

## Generic State Watchdog

Multiple states need safety timeouts (REGISTERING, SYNCING_TIME, TRANSMITTING,
READING_SENSOR). Rather than maintaining separate per-state timeout IDs, a
single generic watchdog can cover all of them.

### Current situation

Two ad-hoc timeout IDs exist in `sensor_mode.h`:
```cpp
uint16_t registration_timeout_id_ = 0;  // guards REGISTERING
uint16_t syncing_time_timeout_id_ = 0;  // guards SYNCING_TIME
```
TRANSMITTING has no watchdog at all. Each has bespoke cancellation code.

### Generic design

Replace both IDs with a single `state_watchdog_id_`. Extract watchdog
arming into a dedicated `armStateWatchdog()` helper so `onStateChange`
remains readable without having to parse timer setup mechanics.

**`sensor_mode.h`** — replace both per-state IDs, add helper declaration,
and add the timeout table:

```cpp
// Replace registration_timeout_id_ and syncing_time_timeout_id_ with:
uint16_t state_watchdog_id_ = 0;

// Private helper
void armStateWatchdog(SensorState state);

// Timeout table — returns 0 for states that need no watchdog
static uint32_t stateWatchdogMs(SensorState state) {
    switch (state) {
        case SensorState::REGISTERING:    return 5'000;
        case SensorState::SYNCING_TIME:   return 5'000;
        case SensorState::READING_SENSOR: return 3'000;
        case SensorState::TRANSMITTING:   return 30'000;
        default:                          return 0;
    }
}
```

**`sensor_mode.cpp`** — call `armStateWatchdog` at the top of `onStateChange`
(one line, intent is self-evident):

```cpp
void SensorMode::onStateChange(SensorState state) {
    armStateWatchdog(state);
    // ... LED patterns, work dispatch, etc.
}
```

Implement the helper separately, keeping all watchdog mechanics in one place:

```cpp
void SensorMode::armStateWatchdog(SensorState state) {
    if (state_watchdog_id_ != 0) {
        task_queue_.cancel(state_watchdog_id_);
        state_watchdog_id_ = 0;
    }
    const uint32_t watchdog_ms = stateWatchdogMs(state);
    if (watchdog_ms == 0) return;

    const uint32_t now = to_ms_since_boot(get_absolute_time());
    state_watchdog_id_ = task_queue_.postDelayed(
        [](void *ctx, uint32_t) -> bool {
            SensorMode *self = static_cast<SensorMode *>(ctx);
            self->state_watchdog_id_ = 0;
            const SensorState current = self->sensor_state_.state();
            logger.error("State watchdog fired in %s",
                         SensorStateMachine::stateName(current));
            // SYNCING_TIME: RTC may still be valid even without a hub response
            if (current == SensorState::SYNCING_TIME) {
                if (rtc_running()) {
                    self->sensor_state_.reportTimeSyncComplete();
                } else {
                    self->sensor_state_.reportSyncTimeout();
                }
            } else {
                self->sensor_state_.reportWatchdogTimeout();  // → READY_FOR_SLEEP
            }
            return true;
        },
        this, now, watchdog_ms, TaskPriority::High);
}
```

Add `reportWatchdogTimeout()` to `SensorStateMachine` with appropriate guards:

```cpp
void SensorStateMachine::reportWatchdogTimeout() {
    logger.error("Watchdog timeout in state %s — forcing READY_FOR_SLEEP",
                 stateName(state_));
    transitionTo(SensorState::READY_FOR_SLEEP);
}
```

### What this eliminates

- `registration_timeout_id_` — gone; cancellation is automatic in `onStateChange`
- `syncing_time_timeout_id_` — gone; same
- The per-state `postDelayed` block in `onStateChange(SYNCING_TIME)` — folded into the generic handler
- The explicit `task_queue_.cancel(registration_timeout_id_)` in the registration success callback becomes redundant (harmless to leave, or remove for clarity)

### What to keep separate

- **LISTENING** uses a fixed 500ms advance timer (always fires, never cancelled).
  This is a scheduled advance, not a safety watchdog — keep it as its own `postDelayed`.
- **READY_FOR_SLEEP (no-PMU)** uses a software timer to simulate the next wake.
  This is also a scheduled advance — keep it separate.

### Optional: pull the table into `SensorStateMachine`

```cpp
// sensor_state_machine.h
static constexpr uint32_t stateWatchdogMs(SensorState state) {
    switch (state) {
        case SensorState::REGISTERING:    return 5'000;
        case SensorState::SYNCING_TIME:   return 5'000;
        case SensorState::READING_SENSOR: return 3'000;
        case SensorState::TRANSMITTING:   return 30'000;
        default:                          return 0;
    }
}
```

This is architecturally cleaner — the state machine owns its timing requirements,
and adding a new state makes it obvious whether a watchdog is needed. `SensorMode`
calls `SensorStateMachine::stateWatchdogMs(state)` instead of its own local table.

---

## Issue Summary

| # | Severity | State | Issue | Impact |
|---|---|---|---|---|
| 1 | **CRITICAL** | DEGRADED_NO_SENSOR | No exit transition; `reportCheckComplete()` rejected | Device halts permanently on sensor init failure; fix: transition to READY_FOR_SLEEP and retry on next wake |
| 2 | **CRITICAL** | AWAITING_TIME | `rtc_set_datetime()` failure — no transition, no timeout | Device halts permanently if RTC set fails |
| 3 | **MEDIUM** | TRANSMITTING | No safety timeout | Device halts if transmit callback never fires |
| 4 | **MEDIUM** | READY_FOR_SLEEP | Scheduled/External wakes don't transition; no PMU = stuck | Device may halt permanently |
| 5 | **LOW** | TIME_SYNCED | Null `sensor_` → no transition | Unlikely but undefended |
| 6 | **LOW** | INITIALIZING | No-PMU path: wasted heartbeat + off-by-one `expected_responses_` | Unnecessary LISTENING state entry |
| 7 | **LOW** | READY_FOR_SLEEP | No software fallback when PMU unavailable | Relies entirely on PMU for wake |

## Recommended Fix Priority

### Immediate (blocks normal operation)

1. **Fix DEGRADED_NO_SENSOR deadlock** — Add a `reportSensorRetry()` transition
   that exits DEGRADED_NO_SENSOR directly to READY_FOR_SLEEP. On the next
   Periodic wake the full cycle restarts and sensor init is retried. Guard with
   a retry counter to escalate to ERROR after N consecutive failures.

2. **Fix AWAITING_TIME deadlock** — Add hub-sync fallback when
   `rtc_set_datetime()` fails in `sensor_mode.cpp:requestTimeSync()`.

### Soon (robustness)

3. **Implement generic per-state watchdog** — Replace `registration_timeout_id_`
   and `syncing_time_timeout_id_` with a single `state_watchdog_id_` armed/cancelled
   in `onStateChange`. Add `stateWatchdogMs()` table covering REGISTERING (5s),
   SYNCING_TIME (5s), READING_SENSOR (3s), TRANSMITTING (30s). Add
   `reportWatchdogTimeout()` to `SensorStateMachine`. See §Generic State Watchdog
   for full design.

4. **Handle all PMU wake reasons** — Transition on Scheduled/External wakes in
   the PMU callback.

5. **Defend TIME_SYNCED null sensor path** — Call `reportSensorInitFailure()`
   when `sensor_` is null in `tryInitSensor()`.

6. **Add READY_FOR_SLEEP software timer (no-PMU)** — Use `postDelayed` in
   `onStateChange(READY_FOR_SLEEP)` when PMU is unavailable to schedule the next
   wake cycle via `reportWakeFromSleep()`.

### Later (cleanup)

7. **Fix no-PMU bootstrap sequence** — Move the heartbeat send to after
   AWAITING_TIME is reached, or gate `expectResponse()` on successful
   `reportHeartbeatSent()`.

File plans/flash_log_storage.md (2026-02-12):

# Flash Log Storage

## Overview

Save debug logs (normally sent to UART/USB serial) to a reserved region of external flash, so they can be retrieved later for post-mortem debugging. Retrieval via USB mass storage mode.

## Feasibility

**Verdict: Fully feasible.** The hardware and software infrastructure already exists to support this.

- The MT25QL01GBBB external flash (128MB) is already present and has a working driver (`ExternalFlash`).
- The `SensorFlashBuffer` already implements a circular buffer pattern on this flash that we can reuse for logs.
- The `Logger` class has a clean extension point for adding a flash sink alongside the existing printf output.
- USB mass storage is achievable via TinyUSB (bundled in the Pico SDK) but requires replacing the default CDC-only USB stack with a composite CDC+MSC device.

## Design

### 1. External Flash Partitioning

The external flash currently dedicates nearly all 128MB to sensor data. The sensor buffer has capacity for ~12 years of data at 30-second intervals -- far more than needed. We can partition a portion for log storage with no practical impact on sensor capacity.

**Current layout:**
```
0x00000000 - 0x00000FFF  Sector 0: SensorFlashBuffer metadata (4KB)
0x00001000 - 0x07FFFFFF  Sensor data region (~128MB)
```

**Proposed layout:**
```
0x00000000 - 0x00000FFF  Sector 0: SensorFlashBuffer metadata (4KB)
0x00001000 - 0x00001FFF  Sector 1: LogFlashBuffer metadata (4KB)
0x00002000 - 0x05FFFFFF  Sensor data region (~96MB, ~8M records, ~7.6 years at 30s)
0x06000000 - 0x07FFFFFF  Log data region (32MB)
```

This requires updating `SensorFlashBuffer::DATA_START_OFFSET` from `0x1000` to `0x2000` and adding a `DATA_END_OFFSET` constant (currently it uses the full flash size).

**Log region capacity:**
- 32MB / 128 bytes per record = 262,144 log entries
- At ~1 log/second average: ~3 days of continuous logging
- At normal operation (~1 log every few seconds): weeks of history

### 2. Log Record Format

Fixed-size 128-byte records for simplicity and alignment with flash page boundaries (2 records per 256-byte page, 32 records per 4KB sector).

```cpp
struct __attribute__((packed)) LogRecord {
    uint32_t timestamp;     // 4 bytes  - ms since boot (or unix time if RTC valid)
    uint8_t  level;         // 1 byte   - LogLevel enum value
    char     module[11];    // 11 bytes - module name, null-terminated
    char     message[108];  // 108 bytes - message text, null-terminated
    uint16_t sequence;      // 2 bytes  - rolling sequence number
    uint16_t crc16;         // 2 bytes  - CRC16-CCITT integrity check
};                          // Total: 128 bytes

static_assert(sizeof(LogRecord) == 128, "LogRecord must be 128 bytes");
```

### 3. LogFlashBuffer

A new class modeled on `SensorFlashBuffer`, but simplified for log entries.

```cpp
class LogFlashBuffer {
public:
    // Flash layout constants
    static constexpr uint32_t METADATA_OFFSET = 0x00001000;  // Sector 1
    static constexpr uint32_t DATA_START = 0x06000000;
    static constexpr uint32_t DATA_END = 0x08000000;  // 128MB boundary
    static constexpr uint32_t DATA_SIZE = DATA_END - DATA_START;  // 32MB
    static constexpr uint32_t MAX_RECORDS = DATA_SIZE / sizeof(LogRecord);

    explicit LogFlashBuffer(ExternalFlash& flash);

    bool init();
    bool writeLog(LogLevel level, const char* module, const char* message);
    bool readRecord(uint32_t index, LogRecord& record);
    uint32_t getRecordCount() const;
    bool flush();
    bool reset();

private:
    ExternalFlash& flash_;
    LogFlashMetadata metadata_;
    // RAM write buffer: accumulate records before flushing a full page
    LogRecord page_buffer_[2];  // 256 bytes = 1 flash page
    uint8_t page_buffer_count_;
    bool initialized_;
    Logger logger_;
};
```

**Key behaviors:**
- Circular buffer: oldest logs overwritten when full
- Page-buffered writes: accumulate 2 records (256 bytes = 1 page) in RAM before writing to flash, reducing flash operations
- Sector erase handled automatically on wrap-around (erase next sector before writing to it)
- CRC16 per record for integrity validation on read
- Metadata persisted to its own sector with flush-on-demand
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

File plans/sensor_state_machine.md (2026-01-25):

# Sensor Mode State Machine

## Problem Statement

The current SensorMode has scattered boolean flags (`rtc_synced_`, `sensor_initialized_`, `pmu_available_`, etc.) and conditional checks that create bugs:

1. **Invalid state combinations**: `rtc_synced_ = true` was set without `rtc_running()` being true
2. **Silent failures**: Sensor init failures weren't reported because the error check assumed init was attempted
3. **Scattered preconditions**: Each function checks its own preconditions inconsistently
4. **Hard to reason about**: No clear picture of valid states and transitions

The TaskQueue helps with task scheduling but doesn't enforce state invariants.

## Proposed Solution: State Machine

A state machine that:
1. Defines explicit states with clear semantics
2. Enforces preconditions on every transition
3. Centralizes state-dependent logic
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

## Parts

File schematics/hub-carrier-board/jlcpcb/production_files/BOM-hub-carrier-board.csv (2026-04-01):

Comment | Designator | Footprint | LCSC | Quantity
0R | R102 | R_0402_1005Metric | C17168 | 1
100k | R704 | R_0402_1005Metric | C25741 | 1
100n | C706,C712 | C_0402_1005Metric | C1525 | 2
100nF | C2 | C_0805_2012Metric_Pad1.18x1.45mm_HandSolder | C49678 | 1
100uF | C702 | CP_EIA-3528-21_Kemet-B | C122271 | 1
10k | R104,R705 | R_0402_1005Metric | C25744 | 2
10u | C701,C703,C704,C705,C708,C709,C710,C711 | C_0805_2012Metric | C15850 | 8
2.2uH | L701 | L_Coilcraft_XAL5030-XXX | C5349681 | 1
2k2 | R501,R502,R605,R606,R706,R707 | R_0402_1005Metric | C25879 | 6
4.7nF | C707 | C_0402_1005Metric | C106208 | 1
470 | C1 | CP_Elec_6.3x7.7 | C2827940 | 1
4u7 | C601 | C_0805_2012Metric | C1779 | 1
5.1K | R20,R21 | C_0402_1005Metric | C25905 | 2
AP22653W6 | U701 | SOT-23-6 | C2158037 | 1
AP3441SHE-7B | U702 | DFN-8-1EP_2x2mm_P0.5mm_EP1.05x1.75mm | C2072094 | 1
ASEK-32.768KHZ-L-R-T | U703 | Crystal_SMD_3225-4Pin_3.2x2.5mm | C2650753 | 1
Bus_M.2_Socket_M | J701 | M.2 M Key socket_2230_2242 | C841666 | 1
ComputeModule5-CM5 | J101,J102 | Raspberry-Pi-5-Compute-Module_GPIO | C6782225 | 2
GPIO1 | J1 | IDC-Header_2x06_P2.54mm_Vertical | C9136 | 1
GREEN | D605,D606,D702 | LED-SMD_L1.7-W0.6-RD | C2286 | 3
I2C | J502 | JST_SH_BM04B-SRSS-TB_1x04-1MP_P1.00mm_Vertical | C160390 | 1
MK-11C04-G013 | SW101 | SW-SMD_MK-11C04-G013 | C778185 | 1
RCLAMP0502BA | D502,D701 | SOT-416 | C117553 | 2
SM02B-SRSS-TB (LF)(SN) | CN1 | CONN-SMD_2P-P1.00_SM02B-SRSS-TB-LF-SN | C160402 | 1
SN74LVC1G14DBVR | U602 | SOT-353_SC-70-5 | C35740 | 1
SPI | J503 | JST_SH_BM10B-SRSS-TB_1x10-1MP_P1.00mm_Vertical | C265443 | 1
TS-1010A-B | SW501 | SW-SMD_TS-1010A-B | C381059 | 1
USB_C_Receptacle_USB2.0_16P | J5 | USB_C_Receptacle_G-Switch_GT-USB-7051x | C2843970 | 1
M.2 Solder Nut | M702 | MountingHole_3mm_Pad |  | 1
PWR | J2 | JST_PH_B2B-PH-K_1x02_P2.00mm_Vertical |  | 1
15k | R3 | R_0402_1005Metric |  | 1

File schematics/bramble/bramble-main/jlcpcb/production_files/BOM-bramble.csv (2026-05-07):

Comment | Designator | Footprint | LCSC | Quantity
100 | R2 | R_0805_2012Metric | C17408 | 1
100 | R14,R15 | C_0402_1005Metric | C25076 | 2
100nF | C13,C16,C17,C18,C19,C20,C21,C22,C23,C24 | C_0402_1005Metric | C1525 | 10
100nF | C4,C5,C8 | C_0805_2012Metric | C28233 | 3
100nF | C27 | C_0402_1005Metric | C49678 | 1
10k | R10,R5,R9 | R_0805_2012Metric | C17414 | 3
10k | R11,R12 | C_0402_1005Metric | C25744 | 2
10pF | C10,C9 | C_0805_2012Metric | C1839 | 2
10uF | C1 | C_0805_2012Metric | C15850 | 1
15p | C25,C26 | C_0402_1005Metric | C1548 | 2
1K | R16,R17,R21,R22 | C_0402_1005Metric | C11702 | 4
1N4148W | D1 | D_SOD-123 | C81598 | 1
1k | R1,R3,R6 | R_0805_2012Metric | C17513 | 3
1uF | C6,C7 | C_0805_2012Metric | C28323 | 2
20k | R7 | R_0805_2012Metric | C4328 | 1
22uF | C2 | C_0805_2012Metric | C45783 | 1
27 | R18,R19 | R_0603_1608Metric | C25190 | 2
3.3uH | L1 | L_Murata_DFE201610P | C42411119 | 1
33 | R13 | C_0402_1005Metric | C25105 | 1
4.7uF | C3 | C_0805_2012Metric | C1779 | 1
4.7uF | C11,C12,C14,C15 | C_0402_1005Metric | C23733 | 4
5.1K | R20 | C_0402_1005Metric | C25905 | 1
8.2k | R8 | R_0805_2012Metric | C17828 | 1
ABM8-272-T3 | Y2 | Crystal_SMD_3225-4Pin_3.2x2.5mm | C20625731 | 1
BOOT | SW1 | SW_SPST_EVQP2_MiddlePushTravel_H2.5mm | C528967 | 1
Conn_01x05_Pin | J1 | JST_EH_B5B-EH-A_1x05_P2.50mm_Vertical | C160256 | 1
Crystal | Y1 | Crystal_SMD_3215-2Pin_3.2x1.5mm | C182057 | 1
FM24CL16B-GTR | U4 | SOIC-8-1EP_3.9x4.9mm_P1.27mm_EP2.29x3mm | C31082 | 1
GPIO1 | J6 | IDC-Header_2x06_P2.54mm_Vertical | C9136 | 1
GPIO2 | J7 | IDC-Header_2x06_P2.54mm_Vertical | C9136 | 1
GPIO3 | J8 | IDC-Header_2x06_P2.54mm_Vertical | C9136 | 1
MCP1700x-120xxMB | U3 | SOT-89-3_Handsoldering | C57883 | 1
MT25QL01GBBB8ESF-0SIT | U8 | SOIC-16W-12_7.5x10.3mm_P1.27mm | C427722 | 1
NiceRF Lora1262 | U5 | HOPERF_RFM9XW_SMD | C5356643 | 1
Opamp_Quad | U1 | TSSOP-14_4.4x5mm_P0.65mm | C2902316 | 1
RESET | SW2 | SW_SPST_EVQP2_MiddlePushTravel_H2.5mm | C528967 | 1
RP2350_80QFN | U6 | RP2350-QFN-80-1EP_10x10_P0.4mm_EP3.4x3.4mm_ThermalVias | C42415655 | 1
RPI SWD | J3 | JST_SH_BM03B-SRSS-TB_1x03-1MP_P1.00mm_Vertical | C160389 | 1
STM32L031F6P6TR | U2 | TSSOP-20_4.4x6.5mm_P0.65mm | C2054042 | 1
TPSM861253RDXR | VR1 | VREG_TPSM861253RDXR | C31183817 | 1
UART | J2 | JST_SH_BM03B-SRSS-TB_1x03-1MP_P1.00mm_Vertical | C160389 | 1
USB_C_Receptacle_USB2.0_16P | J5 | USB_C_Receptacle_G-Switch_GT-USB-7051x | C2843970 | 1
W25Q16JVSS | U7 | SOIC-8_5.3x5.3mm_P1.27mm | C131025 | 1
Series | JP1 | TestPoint_2Pads_Pitch2.54mm_Drill0.8mm |  | 1
Parallel 1 | JP2 | TestPoint_2Pads_Pitch2.54mm_Drill0.8mm |  | 1
Parallel 2 | JP3 | TestPoint_2Pads_Pitch2.54mm_Drill0.8mm |  | 1
TAP TEST | TP5 | TestPoint_Pad_1.5x1.5mm |  | 1
U.FL | J4 | U.FL_Molex_MCRF_73412-0110_Vertical |  | 1
0.1 | R4 | R_Axial_DIN0414_L11.9mm_D4.5mm_P15.24mm_Horizontal |  | 1
PMU SUPPLY TEST | TP6 | TestPoint_Pad_1.5x1.5mm |  | 1
10k | R23 | C_0402_1005Metric |  | 1
3V3 TEST | TP1 | TestPoint_Pad_1.5x1.5mm |  | 1
RX_TEST | TP2 | TestPoint_Pad_1.5x1.5mm |  | 1
TX_TEST | TP3 | TestPoint_Pad_1.5x1.5mm |  | 1
MAINS TEST | TP4 | TestPoint_Pad_1.5x1.5mm |  | 1

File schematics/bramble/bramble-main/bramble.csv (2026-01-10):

Id | Designator | Footprint | Quantity | Designation | Supplier and ref
1 | RPI_STATUS | LED_WS2812B-2020_PLCC4_2.0x2.0mm | 1 | WS2812B_SK6805_1515
2 | STM_STATUS | LED_D3.0mm-3 | 1 | LED_Dual_AKA
3 | IC1 | RP2040-QFN-56 | 1 | RP2040_QFN56
4 | STM_DEBUG | JST_EH_B5B-EH-A_1x05_P2.50mm_Vertical | 1 | Conn_01x05_Pin
5 | PWR1 | JST_XH_B3B-XH-AM_1x03_P2.50mm_Vertical | 1 | Conn_01x03_Pin
6 | J1 | USB_C_Receptacle_GCT_USB4110 | 1 | USB_C_Receptacle_USB2.0_16P
7 | J2 | U.FL_Molex_MCRF_73412-0110_Vertical | 1 | U.FL
8 | BOOT | SW_SPST_EVQP2_MiddlePushTravel_H2.5mm | 1 | BOOT
9 | RESET | SW_SPST_EVQP2_MiddlePushTravel_H2.5mm | 1 | RESET
10 | U$1,U$2,U$3,U$4 | MountingHole_2.5mm_Pad | 4 | MOUNTINGHOLE2.5
11 | C12,C18,C15,C16,C22,C5,C4 | C_0805_2012Metric | 7 | 1uF
12 | C17,C20,C19,C14,C13,C9,C21 | C_0805_2012Metric | 7 | 0.1uF
13 | U6 | SOIC-16W-12_7.5x10.3mm_P1.27mm | 1 | MT25QL01GBBB8ESF-0SIT
14 | R4 | C_0805_2012Metric | 1 | 10k
15 | U4 | HOPERF_RFM9XW_SMD | 1 | RFM95W-915S2
16 | R17,R10,R5,R7 | R_0805_2012Metric | 4 | 1k
17 | VR1 | VREG_TPSM861253RDXR | 1 | TPSM861253RDXR
18 | J3 | PinHeader_2x06_P2.54mm_Vertical | 1 | Conn_02x06_Odd_Even
19 | Q1 | SOT-23 | 1 | DMN3300U
20 | R22,R21 | R_0805_2012Metric | 2 | 22 ohm
21 | R23,R24 | R_0805_2012Metric | 2 | 5.1K
22 | U5 | SOIC-8_5.3x5.3mm_P1.27mm | 1 | W25Q16JVSS
23 | RPI_DEBUG1 | PinHeader_1x03_P2.54mm_Vertical | 1 | Conn_01x03
24 | R3 | C_0805_2012Metric | 1 | 100k
25 | R1,R6 | R_0805_2012Metric | 2 | 100
26 | R25,R19,R20,R16 | R_0805_2012Metric | 4 | 10K
27 | R2,R9,R15 | R_0805_2012Metric | 3 | 10k
28 | SW1 | SW_SPST_EVQP2_MiddlePushTravel_H2.5mm | 1 | STM_RESET
29 | R18 | R_0805_2012Metric | 1 | 1K
30 | R8 | R_Axial_DIN0414_L11.9mm_D4.5mm_P15.24mm_Horizontal | 1 | 0.1
31 | Q2 | SOT-23 | 1 | FDN360P
32 | D1 | D_SOD-123 | 1 | 1N4148W
33 | R13,R14 | R_0805_2012Metric | 2 | 150
34 | C7,C8 | C_0805_2012Metric | 2 | 10pF
35 | U2 | TSSOP-20_4.4x6.5mm_P0.65mm | 1 | STM32L031F6P6TR
36 | Y2 | Crystal_SMD_Abracon_ABM3-2Pin_5.0x3.2mm_HandSoldering | 1 | Crystal
37 | C3,C6,C2 | C_0805_2012Metric | 3 | 100nF
38 | TPS_C_OUT1 | C_0805_2012Metric | 1 | 22uF
39 | U1 | TSSOP-14_4.4x5mm_P0.65mm | 1 | Opamp_Quad
40 | R12 | R_0805_2012Metric | 1 | 8.2k
41 | C10,C11 | C_0805_2012Metric | 2 | 8pF
42 | R11 | R_0805_2012Metric | 1 | 20k
43 | Y1 | Crystal_SMD_3215-2Pin_3.2x1.5mm | 1 | Crystal
44 | U3 | SOT-89-3_Handsoldering | 1 | MCP1700x-120xxMB
45 | TPS_C_IN1 | C_0805_2012Metric | 1 | 10uF
46 | C1 | C_0805_2012Metric | 1 | 4.7uF

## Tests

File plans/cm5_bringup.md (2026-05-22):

# CM5 Carrier Board Bringup

## Context

Custom CM5 carrier board is not booting cleanly on first attempts. Debug UART at TP35/TP36 (DEBUG_UART_TX/RX) + TP46 (GND), 115200 baud, has proven the module executes and reaches the kernel handoff via BL31, but kernel output is silent because the default `serial0` alias does not map to the Pi 5/CM5 dedicated debug UART (UART10 / `ttyAMA10`).

The "known good" NVMe (cloned from SD on the original Pi 5 hub) boots on both the Pi 5 and is presumed to boot on the CM5. A fresh Pi OS image flashed directly to NVMe did **not** boot on the Pi 5 (reasons unclear — possibly first-boot state / NVMe detection timing). So we will clone SD → NVMe instead of flashing a fresh image, matching the known-working recipe.

## Goal

1. Boot the CM5 carrier reliably from NVMe.
2. Get kernel UART output on TP35/TP36 so we can diagnose any remaining issues.
3. Make it easy to swap drives between Pi 5 and CM5 without bricking the hub.

## Steps

### 1. Change boot order on the Pi 5 hub (SD preferred)

Run on the hub:
```bash
sudo rpi-eeprom-config --edit
```
Change `BOOT_ORDER=0xf146` → `BOOT_ORDER=0xf641`.
Reads right-to-left: `1`=SD first, `4`=USB, `6`=NVMe, `f`=restart.
Save and reboot.

**Rationale**: with SD first, swapping NVMes in/out won't brick the hub — it always falls back to SD.

### 2. Clone SD → NVMe on the Pi 5

With the target NVMe plugged in (the one we want to use in the CM5):
```bash
sudo apt install -y rpi-clone
sudo rpi-clone nvme0n1
```

`rpi-clone` handles partition sizing, filesystem resize, and regenerates partition UUIDs so the clone boots cleanly.

Fallback (manual):
```bash
sudo dd if=/dev/mmcblk0 of=/dev/nvme0n1 bs=4M status=progress conv=fsync
sudo parted /dev/nvme0n1 resizepart 2 100%
sudo resize2fs /dev/nvme0n1p2
```

### 3. Apply debug-UART kernel config to the cloned NVMe

While still on the Pi 5 (NVMe plugged in, hub booted from SD):
```bash
sudo mkdir -p /mnt/boot
sudo mount /dev/nvme0n1p1 /mnt/boot

# Enable kernel UART console on CM5 dedicated debug UART
sudo sed -i 's|console=serial0,115200|earlycon console=ttyAMA10,115200|' /mnt/boot/cmdline.txt

# If the cloned cmdline doesn't have console=serial0, append the console args instead:
# sudo sed -i 's|$| earlycon console=ttyAMA10,115200|' /mnt/boot/cmdline.txt

# Ensure enable_uart=1 is present
grep -q "^enable_uart=1" /mnt/boot/config.txt || echo "enable_uart=1" | sudo tee -a /mnt/boot/config.txt

cat /mnt/boot/cmdline.txt
sudo umount /mnt/boot
```

**Why**: Bootloader UART works via fixed debug UART routing, but the kernel's `console=serial0` alias maps to UART0/GPIO14-15, not the debug UART at TP35/TP36. Using `ttyAMA10` targets UART10 directly. `earlycon` gets output from the very first kernel instruction, before the full serial driver loads.

### 4. Move NVMe to CM5 and capture UART

1. Safely shut down the hub, remove NVMe.
2. Install NVMe in the CM5 carrier's M.2 slot.
3. Connect debug probe at 115200 8N1:
   - Probe RX ← TP35 (CM5 TX)
   - Probe TX → TP36 (CM5 RX, optional)
   - Probe GND ↔ TP46
4. Power on. Expect to see:
   - Bootloader banner (`BOOTSYS release ...`)
   - PCIe scan + NVMe enumeration
   - Kernel loaded, BL31 banner
   - **Kernel boot messages** (new — this is what we're solving for)
   - Systemd startup
   - Login prompt

### 5. If kernel still silent after BL31

Fallbacks to try, in order:
1. Try `console=ttyS0,115200` instead of `ttyAMA10` (8250 driver).
2. Add `loglevel=8 debug ignore_loglevel` to cmdline.
3. Add `uart_2ndstage=1` to config.txt for more bootloader verbosity.
4. Plan to bodge USB slave + nRPIBOOT to enable `rpiboot` — allows editing EEPROM (`UART_CONSOLE=1` for guaranteed bootloader UART on all boot stages) and flashing eMMC directly.

## Done criteria

- Hub boots reliably from SD regardless of which NVMe is inserted.
- CM5 carrier boots the cloned NVMe.
- Kernel boot messages visible on TP35 at 115200 baud.
- Login prompt appears on UART (no network available on this carrier — no wifi, no Ethernet).

## Known gotchas

- CM5 module has **no wifi** on this SKU — UART is the only diagnostic channel.
- `POWER_OFF_ON_HALT=1` in EEPROM: if the OS requests shutdown, the module powers off and the next boot may land in `partition 63` (halt state) until power is cycled. This is normal.
- `serial0` ≠ debug UART on Pi 5/CM5. Always use `ttyAMA10` for kernel console on TP35/36.
- Pre-existing working NVMe uses SD-derived install — do not wipe it until the cloned one is proven.

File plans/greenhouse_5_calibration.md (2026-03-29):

# Increment 5: Interactive Calibration

## Goal
Allow users to calibrate the curtain travel time through an interactive procedure in the dashboard.

## Calibration Procedure
1. User clicks "Calibrate" in dashboard
2. Node drives curtain fully closed (REVERSE for max_motor_run_ms)
3. Node pauses briefly, then drives curtain open (FORWARD)
4. Timer starts counting
5. User watches curtain physically, clicks "Stop" when fully open
6. Node records elapsed time as `travel_time_ms_`, persists to flash config
7. Node sends calibration-complete event to hub with recorded travel time

## Firmware Changes

### `src/hal/curtain_controller.h` / `.cpp`
- Implement `startCalibration()` state machine:
  - CALIBRATING_CLOSE → motor runs in close direction for max_motor_run_ms
  - CALIBRATING_PAUSE → brief pause (1s)
  - CALIBRATING_OPEN → motor runs in open direction, timer counting
  - On `stop()` during CALIBRATING_OPEN: record elapsed as travel_time_ms
- Add `persistTravelTime()` — write travel_time_ms to a flash config sector
- Add `loadTravelTime()` — read from flash on startup

### `src/modes/greenhouse_mode.cpp`
- Handle `CMD_CALIBRATE` in `onActuatorCommand()` → call `curtain_controller_.startCalibration()`
- `onLoop()`: `update()` already handles calibration state transitions
- Send calibration-complete event with recorded travel time

## API Changes

### `api/app.py`
- Add `PUT /api/nodes/<address>/curtain/config` endpoint:
  - Body: `{"travel_time_seconds": N}`
  - Alternative to interactive calibration: user enters time manually
  - Sends config command to node via hub

## Dashboard Changes

### `dashboard/src/components/CurtainControl.tsx`
- Add "Calibrate" button that opens a calibration wizard:
  1. "Starting calibration... curtain closing" (progress indicator)
  2. "Curtain opening — click Stop when fully open" (prominent Stop button)
  3. "Calibration complete! Travel time: Xs" (confirmation)
- Add manual travel time input as alternative
- Show current calibrated travel time

## Verification
1. Click Calibrate → curtain closes fully, then opens
2. Click Stop when fully open → travel time recorded
3. Subsequent open/close operations use calibrated time and stop correctly
4. Travel time persists across reboots
5. Manual time entry via dashboard also works

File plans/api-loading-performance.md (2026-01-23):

# API Loading Performance Optimization Plan

## Overview

Optimize the sensor data API to reduce load times when viewing the 24-hour chart by addressing these bottlenecks:
1. Statistics query scanning all historical data
2. No server-side downsampling (sending up to 5000 points)
3. No HTTP response compression
4. Redundant fields in JSON responses

## Current State

- **Statistics endpoint**: Scans entire node history for min/max/avg
- **Sensor data endpoint**: Returns up to 5000 raw readings with redundant fields
- **No compression**: Large JSON payloads sent uncompressed
- **Frontend**: Already makes concurrent requests for stats and chart data (`Promise.all`)

## Changes

### 1. Add Time Filters to Statistics Query

**Files:** `api/database.py`, `api/app.py`

**Current behavior (`database.py:454-466`):**
```python
SELECT MIN(temperature_centidegrees), MAX(...), AVG(...)
FROM sensor_readings
WHERE node_address = ?  # No time filter
```

**New behavior:**
- Add optional `start_time` and `end_time` parameters to `get_node_statistics()`
- Pass time range from API endpoint to database method
- Update SQL query to filter by time range when provided

**API change:**
```
GET /api/nodes/{addr}/statistics?start_time=X&end_time=Y
```

**Database method signature:**
```python
def get_node_statistics(
    self,
    node_address: int,
    start_time: Optional[int] = None,
    end_time: Optional[int] = None
) -> Optional[dict]
```

---

### 2. Add Server-Side Downsampling

**Files:** `api/database.py`, `api/app.py`

**Goal:** Return at most ~500-800 points regardless of time range, which is sufficient for chart display.

**Approach:** Use LTTB (Largest-Triangle-Three-Buckets) algorithm or simple bucket averaging.

For simplicity, implement **bucket averaging**:
- Divide time range into N buckets (e.g., 500)
- For each bucket, return average temperature/humidity and bucket midpoint timestamp
- This preserves trends while dramatically reducing payload size

**New endpoint parameter:**
```
GET /api/nodes/{addr}/sensor-data?start_time=X&end_time=Y&downsample=500
```

When `downsample` is specified:
- Calculate bucket size: `(end_time - start_time) / downsample`
- Group readings into buckets by timestamp
- Return one averaged point per bucket

**SQL approach (DuckDB supports window functions):**
```sql
SELECT
    node_address,
    (timestamp / bucket_size) * bucket_size as bucket_timestamp,
    AVG(temperature_centidegrees) as temperature_centidegrees,
    AVG(humidity_centipercent) as humidity_centipercent,
    COUNT(*) as sample_count
FROM sensor_readings
WHERE node_address = ? AND timestamp >= ? AND timestamp <= ?
GROUP BY node_address, bucket_timestamp
ORDER BY bucket_timestamp
```

**Response format for downsampled data:**
```json
{
  "node_address": 42,
  "count": 500,
  "downsampled": true,
  "bucket_seconds": 172,
  "readings": [
    {
      "timestamp": 1705507200,
      "temperature_celsius": 22.5,
      "humidity_percent": 65.0,
      "sample_count": 3
    }
  ]
}
```

---

### 3. Enable Gzip Compression

**Files:** `api/app.py`, `api/requirements.txt` (if needed)

**Approach:** Use Flask-Compress middleware

**Installation:**
```bash
pip install flask-compress
```

**Implementation:**
```python
from flask_compress import Compress

app = Flask(__name__)
Compress(app)  # Automatically compresses responses > 500 bytes
```

**Configuration (optional):**
```python
app.config['COMPRESS_MIMETYPES'] = ['application/json']
app.config['COMPRESS_MIN_SIZE'] = 500
```

This provides automatic gzip/deflate compression for all JSON responses.

---

### 4. Remove Redundant Fields from JSON Response

**Files:** `api/database.py`

**Current `to_dict()` output:**
```python
{
    'node_address': ...,
    'device_id': ...,
    'timestamp': ...,
    'temperature_celsius': ...,    # Derived
    'humidity_percent': ...,       # Derived
    'temperature_raw': ...,        # Redundant - remove
    'humidity_raw': ...,           # Redundant - remove
    'flags': ...,
    'received_at': ...
}
```

**New output:**
```python
{
    'timestamp': ...,
    'temperature_celsius': ...,
    'humidity_percent': ...,
    'flags': ...,
}
```

For chart data specifically, we can remove:
- `node_address` - already known from the request
- `device_id` - not needed for charts
- `temperature_raw` / `humidity_raw` - redundant
- `received_at` - not needed for charts

**Approach:** Add a `compact` parameter or create a separate `to_chart_dict()` method:
```python
def to_chart_dict(self) -> dict:
    """Minimal representation for chart display."""
    return {
        'timestamp': self.timestamp,
        'temperature_celsius': self.temperature_celsius,
        'humidity_percent': self.humidity_percent,
    }
```

Use this for the sensor-data endpoint when used for charts.

---

### 5. Verify Concurrent Requests (Frontend)

**Files:** `dashboard/src/components/NodeDetail.tsx`

**Current implementation (already correct):**
```typescript
const [sensorData, stats] = await Promise.all([
  getNodeSensorData(node.address, { startTime, endTime, limit: 5000 }),
  getNodeStatistics(node.address)
]);
```

**Update needed:** Pass time range to statistics call:
```typescript
const [sensorData, stats] = await Promise.all([
  getNodeSensorData(node.address, { startTime, endTime, downsample: 500 }),
  getNodeStatistics(node.address, { startTime, endTime })
]);
```

**Update `api/client.ts`:**
- Add `downsample` parameter to `getNodeSensorData()`
- Add `startTime`/`endTime` parameters to `getNodeStatistics()`

---

## Implementation Order

1. **Enable gzip compression** - Quickest win, no API changes
2. **Add time filters to statistics** - Backend then frontend
3. **Remove redundant fields** - Backend only, reduces payload ~40%
4. **Add downsampling** - Most complex, biggest impact

## Testing

- Verify chart still renders correctly after each change
- Compare payload sizes before/after (use browser DevTools Network tab)
- Measure load time improvements
- Ensure statistics match expected values for time-filtered queries

## Expected Improvements

| Change | Payload Reduction | Notes |
|---|---|---|
| Gzip compression | ~70-80% | Automatic for JSON |
| Remove redundant fields | ~40% | Fewer bytes per reading |
| Downsampling (5000→500) | ~90% | 10x fewer readings |
| **Combined** | **~97%** | From ~1.2MB to ~30-40KB |

Time-filtered statistics will also be faster as it scans less data.

## Risks

- **Downsampling**: May hide brief spikes/dips in data. Mitigate by keeping raw export available.
- **Compact format**: Breaking change for any external API consumers. Consider versioning or opt-in via query param.

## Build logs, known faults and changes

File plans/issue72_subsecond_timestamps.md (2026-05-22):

# Issue #72: Add Subsecond Precision to RTC-Synced Log Timestamps

## Problem Summary

Currently, log timestamps lose millisecond precision after RTC sync:
- **Before RTC sync**: `[+Xms]` - relative time with millisecond precision
- **After RTC sync**: `[2026-01-31 02:53:13]` - absolute time with only second precision

This makes it difficult to profile wake cycles (~400ms) and debug timing-sensitive issues.

## Proposed Solution

Change the absolute timestamp format from:
```
[2026-01-31 02:53:13]
```
to:
```
[2026-01-31 02:53:13.045]
```

## Technical Approach

### Synchronized Millisecond Tracking

The RTC and system timer are independent clocks. To get accurate milliseconds within each RTC second, we track when the RTC was synced:

1. When `rtc_set_datetime()` is called, record the system timer value
2. On each log, calculate elapsed time since sync
3. The ms within current second = `(elapsed_ms) % 1000`

This works because both the RTC and elapsed calculation advance at 1000ms per second.

### Implementation

**1. Add to `Logger` class (`src/hal/logger.h`):**

```cpp
private:
    static uint64_t rtc_sync_us_;  // System time (us) when RTC was last synced

public:
    /**
     * @brief Call immediately after rtc_set_datetime() to sync subsecond precision
     */
    static void onRtcSynced() {
        rtc_sync_us_ = to_us_since_boot(get_absolute_time());
    }
```

**2. Update timestamp formatting:**

```cpp
if (rtc_running() && rtc_get_datetime(&dt)) {
    uint32_t ms_in_second = 0;
    if (rtc_sync_us_ > 0) {
        uint64_t elapsed_us = to_us_since_boot(get_absolute_time()) - rtc_sync_us_;
        ms_in_second = (elapsed_us / 1000) % 1000;
    }
    printf("[%04d-%02d-%02d %02d:%02d:%02d.%03lu] ",
           dt.year, dt.month, dt.day, dt.hour, dt.min, dt.sec, ms_in_second);
}
```

**3. Initialize static member (`src/hal/logger.cpp`):**

```cpp
uint64_t Logger::rtc_sync_us_ = 0;
```

**4. Update RTC set call sites to call `Logger::onRtcSynced()`:**

| File | Line | Context |
|---|---|---|
| `src/modes/application_mode.cpp` | ~128 | After heartbeat response sets RTC |
| `src/modes/hub_mode.cpp` | ~512 | After receiving datetime from Raspberry Pi |
| `src/modes/sensor_mode.cpp` | ~1061 | After receiving datetime from PMU |

## Tasks

- [ ] Add `rtc_sync_us_` static member and `onRtcSynced()` method to Logger
- [ ] Update timestamp formatting to use synchronized milliseconds
- [ ] Initialize static member in logger.cpp
- [ ] Add `Logger::onRtcSynced()` call after `rtc_set_datetime()` in application_mode.cpp
- [ ] Add `Logger::onRtcSynced()` call after `rtc_set_datetime()` in hub_mode.cpp
- [ ] Add `Logger::onRtcSynced()` call after `rtc_set_datetime()` in sensor_mode.cpp
- [ ] Build all variants to verify compilation
- [ ] Test on hardware

## Files Changed

| File | Change |
|---|---|
| `src/hal/logger.h` | Add `rtc_sync_us_`, `onRtcSynced()`, update timestamp format |
| `src/hal/logger.cpp` | Initialize `rtc_sync_us_` static member |
| `src/modes/application_mode.cpp` | Call `Logger::onRtcSynced()` after RTC set |
| `src/modes/hub_mode.cpp` | Call `Logger::onRtcSynced()` after RTC set |
| `src/modes/sensor_mode.cpp` | Call `Logger::onRtcSynced()` after RTC set |

## Example Output

Before:
```
[+1234ms] INFO [SensorMode]: Starting measurement
[+1456ms] INFO [SensorMode]: Temperature: 22.5C
[2026-01-31 02:53:13] INFO [SensorMode]: RTC synced, sending data
[2026-01-31 02:53:13] INFO [SensorMode]: Transmission complete
```

After:
```
[+1234ms] INFO [SensorMode]: Starting measurement
[+1456ms] INFO [SensorMode]: Temperature: 22.5C
[2026-01-31 02:53:13.045] INFO [SensorMode]: RTC synced, sending data
[2026-01-31 02:53:13.312] INFO [SensorMode]: Transmission complete
```

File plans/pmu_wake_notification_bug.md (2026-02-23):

# PMU Wake Notification Bug Investigation

## Problem Statement
The RP2040 receives the CTS (ClearToSend) ACK from the PMU, but the subsequent
WakeNotification never arrives. The RP2040 times out after 1000ms and proceeds
without PMU state restoration.

## Expected Flow
```
RP2040                          STM32 (PMU)
  |                                |
  |-- ClearToSend (0x19) -------->|
  |                                | sets clearToSendReceived_ = true
  |<-------- ACK (0x80) ----------|
  |                                |
  |  (RP2040 starts 1000ms timer) | (main loop dispatches CTS_RECEIVED)
  |                                | → state machine → WAKE_ACTIVE
  |                                | → determineWakeType()
  |                                | → sendWakeNotification()
  |                                |
  |<--- WakeReason (0x84) --------|  <-- THIS NEVER ARRIVES
  |                                |
```

## Root Causes Identified

### Cause 1 (Primary): CTS_TIMEOUT sends WakeNotification before RP2040 is ready

**Location**: `pmu-stm32/Core/Src/pmu_state_machine.cpp:55-59` and `pmu-stm32/Core/Src/main.cpp:793-800`

The CTS_TIMEOUT (2 seconds) in AWAITING_CTS is shorter than the RP2040 boot time.
When the timeout fires, the state machine transitions to WAKE_ACTIVE and sends the
WakeNotification to a RP2040 that hasn't initialized its UART yet. The bytes are
lost on the wire.

**Sequence:**
1. RTC wakes STM32 → transitions to AWAITING_CTS → enables DC/DC
2. RP2040 starts booting (takes >2 seconds including UART init + preamble + CTS)
3. **CTS_TIMEOUT fires after 2s** → AWAITING_CTS → WAKE_ACTIVE
4. STM32 sends WakeNotification (RP2040 UART not initialized yet, bytes lost)
5. RP2040 finishes booting, sends CTS with 300ms preamble
6. STM32 ACKs the CTS (**CTS ack received**)
7. RP2040 starts 1000ms timer waiting for WakeNotification
8. STM32 is already in WAKE_ACTIVE, CTS_RECEIVED is a no-op (reducer returns same state)
9. **No WakeNotification is sent** → RP2040 times out

**Why CTS_RECEIVED is a no-op in WAKE_ACTIVE** (`pmu_state_machine.cpp:68-77`):
```cpp
case PmuState::WAKE_ACTIVE:
    switch (event) {
        case PmuEvent::READY_FOR_SLEEP:
        case PmuEvent::WAKE_TIMEOUT:
            return PmuState::SLEEPING;
        // ...
        default:
            return state;  // CTS_RECEIVED falls here - no transition!
    }
```

Since there's no state transition, `onStateChange` is never called, and
`sendWakeNotification()` is never invoked for the late-arriving CTS.

**Timing analysis:**
- DC/DC enable → RP2040 power-on: ~few ms
- RP2040 boot (Pico SDK init, flash, etc.): ~500-1500ms
- PMU client UART init + 150ms stabilization delay: ~200ms
- Wake preamble (3 x 50ms + 150ms): 300ms
- CTS command TX at 9600 baud: ~6ms
- **Total: ~1200-2200ms** (overlaps or exceeds the 2000ms CTS_TIMEOUT)

### Cause 2 (Secondary): SLEEPING handler race condition with STOP mode re-entry

**Location**: `pmu-stm32/Core/Src/main.cpp:220-226`

When the RP2040 is USB-powered (stays alive after DC/DC disable), it can send CTS
while the STM32 is in SLEEPING state. The CTS is received and ACKed during the
`HAL_Delay(100)` in the SLEEPING handler, but the main loop goes back to STOP mode
without checking the CTS flag.

```cpp
case PmuState::SLEEPING:
    dcdc.disable();
    led.setColor(LED::GREEN);
    HAL_Delay(100);         // <-- CTS can arrive here (UART interrupt)
    led.off();              //     ACK is sent from interrupt context
    enterStopMode();        // <-- Goes to STOP with CTS flag unchecked!
    wakeupFromStopMode();
    break;
```

**Sequence:**
1. STM32 is in SLEEPING state, enters STOP mode
2. RP2040 (USB-powered) sends wake preamble → wakes STM32
3. `wakeupFromStopMode()` runs, main loop restarts
4. State is still SLEEPING, `protocol.isCtsReceived()` → false (CTS not complete yet)
5. SLEEPING handler: `HAL_Delay(100)`
6. **During the delay**: remaining CTS bytes arrive, parsed by UART interrupt,
   `clearToSendReceived_ = true`, ACK sent from interrupt context
7. After delay: `enterStopMode()` → **goes back to STOP without processing CTS flag**
8. RP2040 received ACK, waits for WakeNotification that never comes

The CTS flag is only checked at the **top** of the main loop (`main.cpp:196-199`),
not before `enterStopMode()`.

### Cause 3 (Minor): Shared MessageBuilder between interrupt and main loop contexts

**Location**: `pmu-stm32/Core/Src/pmu_protocol.cpp` - single `builder_` instance

The STM32's `Protocol` class has a single `MessageBuilder builder_` used for both:
- `sendAck()` called from UART RX interrupt context (inside `processReceivedByte`)
- `sendWakeNotification()` called from main loop context (via `onStateChange`)

If a CTS retry arrives while the main loop is building a WakeNotification message,
the `builder_` buffer would be corrupted mid-transmission since `HAL_UART_Transmit`
reads from the same buffer progressively.

This is unlikely in normal operation (RP2040 won't retry after receiving ACK) but
could occur if the ACK was corrupted on the wire, causing the RP2040 to retry
CTS while the STM32 is building/sending the WakeNotification.

## Resolution

After analysis, the cleanest fix addresses both root causes by removing the
`CTS_TIMEOUT` entirely and eliminating the SLEEPING race window.

### Change 1: Remove `CTS_TIMEOUT` — rely on `WAKE_TIMEOUT` as safety net

**Files**: `pmu_state_machine.h`, `pmu_state_machine.cpp`

Removed `CTS_TIMEOUT_MS`, `PmuEvent::CTS_TIMEOUT`, and the CTS timeout check in
`tick()`. The 2-minute `PERIODIC_WAKE_TIMEOUT_MS` is the safety net for the
pathological case where the RP2040 crashes and never sends CTS.

Without `CTS_TIMEOUT`, the PMU stays in `AWAITING_CTS` until the RP2040 finishes
booting (1.2–2.2s) and sends CTS. The state machine then transitions correctly
to `WAKE_ACTIVE` and sends the `WakeNotification`.

### Change 2: Remove `HAL_Delay(100)` from `SLEEPING` handler

**File**: `main.cpp`

The 100ms delay was the entire race window where CTS could arrive during
`SLEEPING` and be ACKed, but the STM32 would still re-enter STOP mode on the
next iteration without processing the CTS flag.

Removing the delay eliminates this window entirely. If CTS arrives after the
STM32 has entered STOP mode, the LPUART start-bit detection wakes the MCU
immediately, and the main loop processes the CTS flag on the next iteration.

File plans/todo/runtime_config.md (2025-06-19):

# Runtime Configuration System - Future Implementation Plan

## Overview
This document outlines a future plan for implementing runtime configuration in the Bramble LoRa farm monitoring system. **This is not currently implemented** - it's a design for future enhancement when remote configuration capabilities become needed.

## Why Runtime Config?
The main value proposition is **remote configuration of deployed field nodes** without physical access. However, this requires infrastructure we don't currently have (WiFi hub connectivity, etc.).

## Current Status: DEFERRED
- **Decision**: Skip runtime config for now, focus on immediate priorities
- **Reason**: Requires infrastructure (WiFi hub) we don't have yet
- **Alternative**: Use compile-time configuration variants for different deployments

---

## Minimal Viable Configuration System (Future)

### Core Principle
Only make configurable what you **can't easily change by reflashing**. The real value is remote configuration via LoRa for deployed nodes in the field.

### High-Value Configurable Parameters

#### 1. LoRa Radio Settings (Regulatory/Performance)
- `frequency` - Different regions (915MHz US vs 868MHz EU)
- `tx_power` - Adjust for range vs power consumption  
- `spreading_factor` - Trade speed vs range

#### 2. Operational Timing (Field Tuning)
- `sensor_interval_ms` - Battery life vs data freshness
- `heartbeat_interval_ms` - Network overhead vs monitoring
- `node_offline_timeout_ms` - How long before marking node dead

#### 3. Network Reliability (Network Conditions)
- `max_retries` - Adjust for network reliability
- `ack_timeout_ms` - Adjust for network latency

### Configuration Structure

```cpp
// src/config/runtime_config.h
struct RuntimeConfig {
    // LoRa Radio (most important for deployed systems)
    uint32_t lora_frequency;        // 915000000 or 868000000
    uint8_t lora_tx_power;          // 2-20 dBm
    uint8_t lora_spreading_factor;  // 7-12
    
    // Timing (second most important)
    uint32_t sensor_interval_ms;    // How often to read sensors
    uint32_t heartbeat_interval_ms; // How often to send heartbeat
    uint32_t node_offline_timeout_ms; // When to mark nodes offline
    
    // Network reliability
    uint8_t max_retries;            // Message retry count
    uint32_t ack_timeout_ms;        // ACK wait time
    
    // Validation
    uint32_t magic;                 // 0xCFG1234
    uint32_t crc32;                 // Data integrity
};
```

### Simple Config Manager

```cpp
class RuntimeConfigManager {
public:
    static RuntimeConfigManager& getInstance();
    
    bool initialize(Flash& flash);
    const RuntimeConfig& get() const { return config_; }
    
    // Remote update via LoRa messages
    bool updateConfig(const RuntimeConfig& new_config);
    bool updateLoRaSettings(uint32_t freq, uint8_t power, uint8_t sf);
    bool updateTimings(uint32_t sensor_ms, uint32_t heartbeat_ms);
    
private:
    RuntimeConfig config_;
    Flash* flash_;
    void setDefaults();
    bool validate(const RuntimeConfig& config) const;
};
```

### LoRa-based Remote Configuration

Add new message type:
```cpp
MSG_TYPE_CONFIG_UPDATE = 0x09

struct ConfigUpdatePayload {
    uint8_t update_type;        // 1=LoRa, 2=Timing, 3=Network
    union {
        struct {
            uint32_t frequency;
            uint8_t tx_power;
            uint8_t spreading_factor;
        } lora;
        struct {
            uint32_t sensor_interval_ms;
            uint32_t heartbeat_interval_ms;
            uint32_t node_offline_timeout_ms;
        } timing;
        struct {
            uint8_t max_retries;
            uint32_t ack_timeout_ms;
        } network;
    };
    uint32_t auth_token;        // Simple authentication
};
```

## Remote Update Workflow

1. **Hub sends config update** to specific node or broadcast
2. **Node validates** the new configuration
3. **Node applies** safe changes immediately (intervals, timeouts)
4. **Node saves** to flash and **ACKs** success
5. **Node reboots** for radio changes (frequency/power) - **only if needed**

## Implementation Priority (When Resumed)

### Phase 1: Core Config (1-2 days)
- Create `RuntimeConfig` structure with defaults
- Add flash save/load with CRC validation  
- Replace current hardcoded timing values
- Test basic functionality

### Phase 2: LoRa Radio Config (1 day)
- Add radio parameter updates
- Handle frequency/power changes (may require restart)
- Test different radio settings

### Phase 3: Remote Updates (2-3 days)
- Add `MSG_TYPE_CONFIG_UPDATE` message handling
- Implement config update protocol with authentication
- Add hub-side config management commands
- Test remote configuration over LoRa

## Key Benefits (When Implemented)

1. **Field Deployment**: Change sensor intervals based on battery life observations
2. **Regional Compliance**: Remotely switch frequency for different countries
3. **Network Optimization**: Tune retry/timeout based on observed network performance
4. **Power Management**: Adjust intervals to extend battery life
5. **Range Optimization**: Tune spreading factor and power for coverage

## What Should Stay Hardcoded

- **GPIO pins** - Hardware-specific, needs reflash anyway
- **SPI frequency** - Hardware-specific, rarely changed
- **Protocol constants** - Changing breaks compatibility
- **Flash layout** - Requires careful planning, reflash safer
- **Address ranges** - Network architecture decision

## Prerequisites for Implementation

1. **Hub connectivity** - WiFi module, Ethernet, or cellular
2. **Hub API** - Web interface or API to send config commands
3. **Authentication** - Secure way to authorize config changes
4. **Field testing** - Validate that remote config is actually needed

## Alternative Approaches (Immediate)

### Option A: Enhanced Build Configs
```cpp
// config_profiles.h
#ifdef CONFIG_PROFILE_US_FARM
    #define LORA_FREQUENCY 915000000
    #define SENSOR_INTERVAL_MS 300000      // 5 min (battery conservative)
    #define TX_POWER 14                    // Lower power
#endif

#ifdef CONFIG_PROFILE_EU_GREENHOUSE  
    #define LORA_FREQUENCY 868000000
    #define SENSOR_INTERVAL_MS 60000       // 1 min (powered nodes)
    #define TX_POWER 20                    // Max range
#endif
```

### Option B: USB Serial Config Interface
```cpp
// When hub connected to computer via USB
config set sensor_interval 300000
config set frequency 868000000
config save
config reboot
```

### Option C: Button-based Physical Config
```cpp
// Hold button during boot = cycle through predefined configs
// LED patterns indicate current config
// Useful for field switching between "summer" vs "winter" settings
```

## Usage Examples (Future)

```cpp
// In main loop
const RuntimeConfig& cfg = RuntimeConfigManager::getInstance().get();

// Use configurable timing
if (current_time - last_sensor_time >= cfg.sensor_interval_ms) {
    // Read sensors
}

// Use configurable radio settings  
lora.setFrequency(cfg.lora_frequency);
lora.setTxPower(cfg.lora_tx_power);

// Use configurable retry logic
messenger.setRetryParams(cfg.max_retries, cfg.ack_timeout_ms);
```

## Files to Create (When Implemented)

**New Files:**
- `src/config/runtime_config.h` - Configuration data structures
- `src/config/config_manager.h/.cpp` - Configuration management class
- `src/config/config_defaults.h` - Default configuration values

**Modified Files:**
- `bramble.cpp` - Replace hardcoded values with config lookups
- `src/lora/sx1276.cpp` - Use config for radio parameters
- `src/lora/reliable_messenger.cpp` - Use config for retry/timeout settings
- `src/lora/message.h` - Add MSG_TYPE_CONFIG_UPDATE
- `CMakeLists.txt` - Add new config source files

---

## Decision Log

**2024-06-19**: Decided to defer runtime configuration implementation
- **Reason**: Requires hub connectivity infrastructure we don't have
- **Alternative**: Focus on immediate TODOs and revisit when hub gets WiFi/network
- **Next Action**: Move to next item in todo list

This plan provides a comprehensive approach for **future implementation** when the supporting infrastructure is available.

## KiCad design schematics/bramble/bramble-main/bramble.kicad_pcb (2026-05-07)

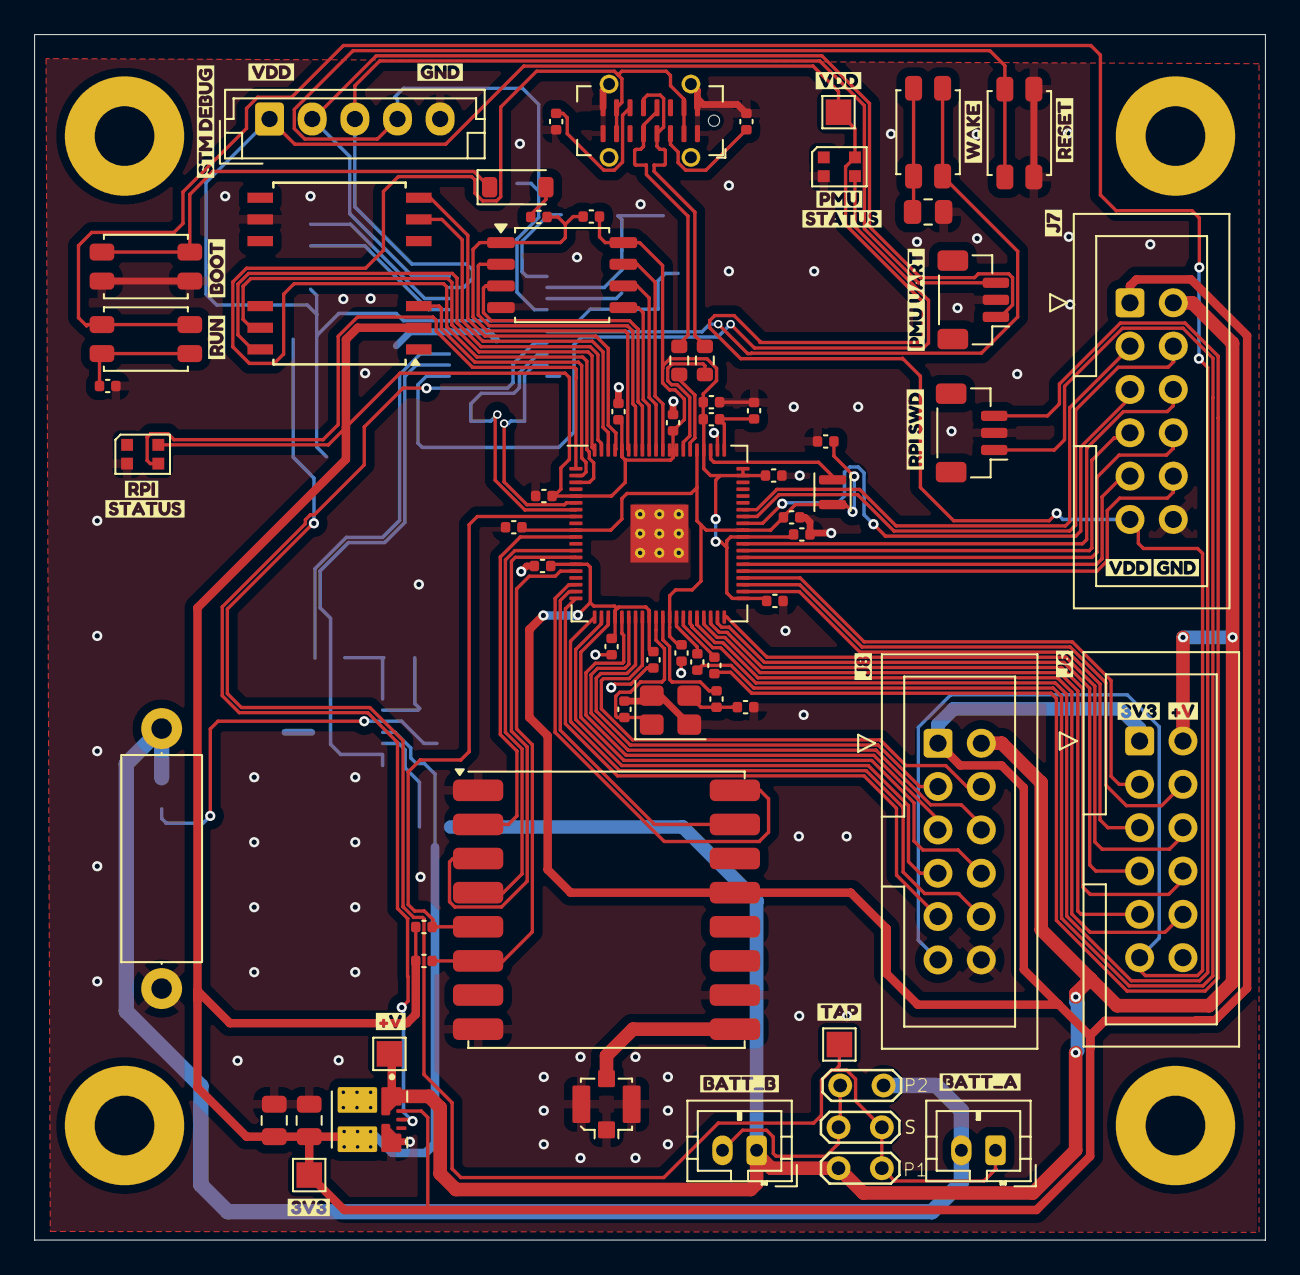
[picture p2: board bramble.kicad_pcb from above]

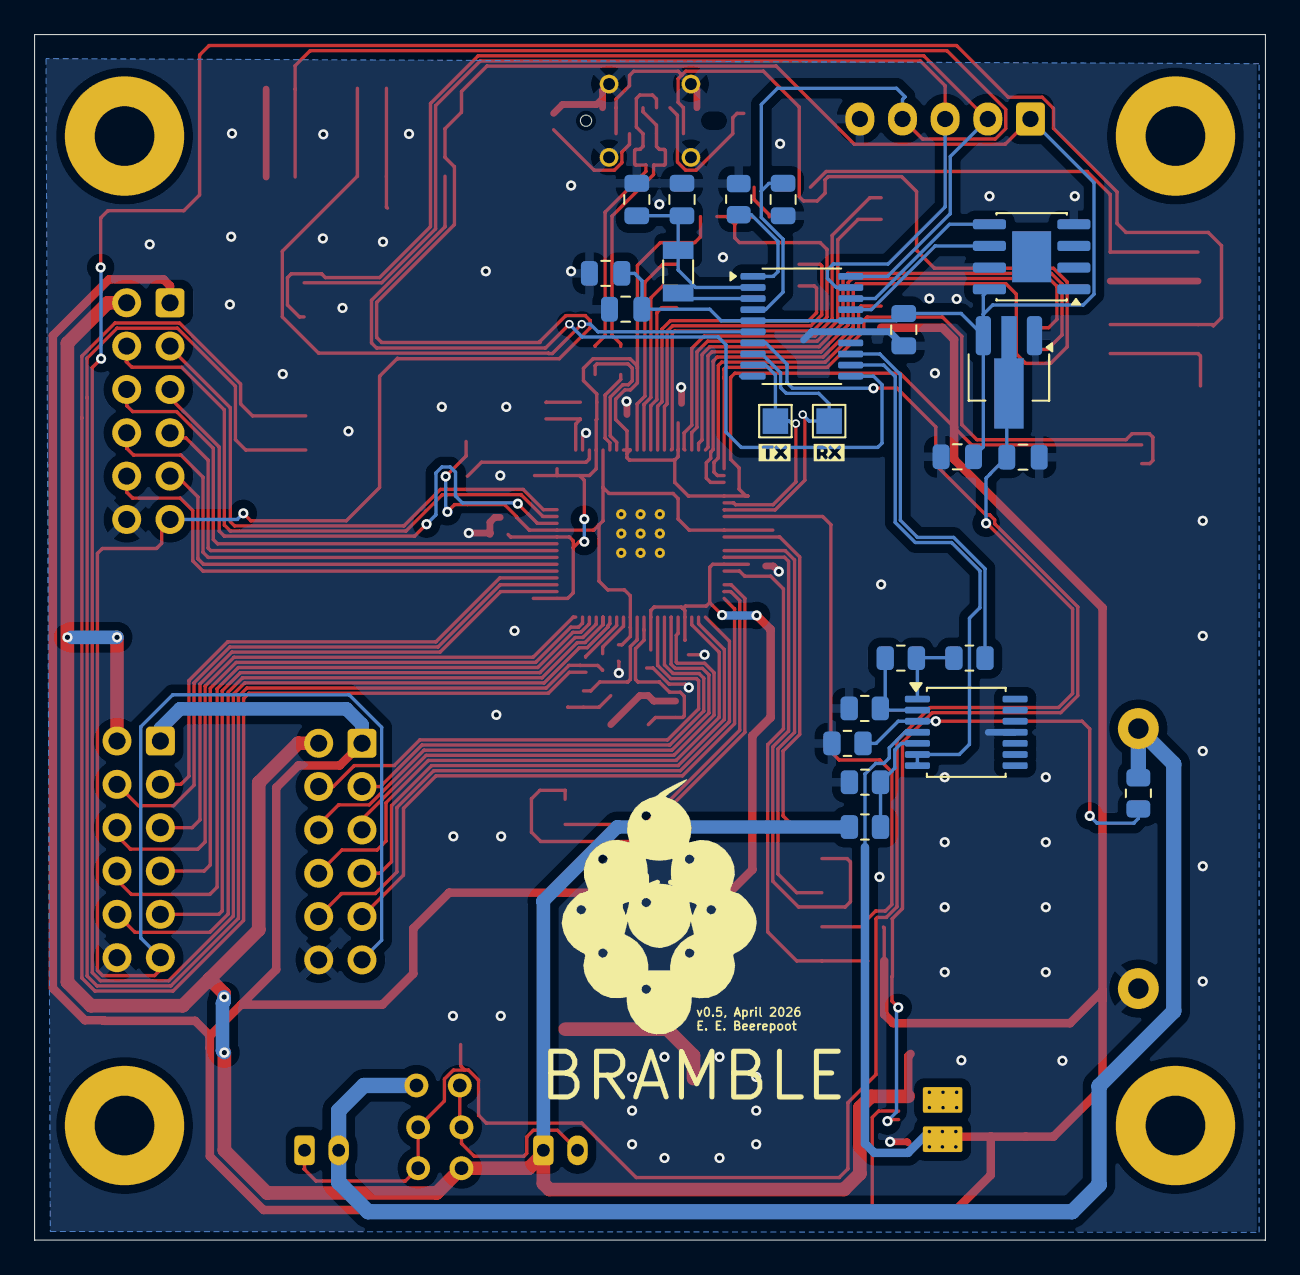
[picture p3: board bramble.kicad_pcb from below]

Board: 2 copper layers, 72.1 x 70.7 mm, 120 parts (25 on the bottom side), 91 nets.

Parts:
C1: 10uF; C_0805_2012Metric
C2: 22uF; C_0805_2012Metric
C3: 4.7uF; C_0805_2012Metric
C4, C5, C8: 100nF; C_0805_2012Metric
C6, C7: 1uF; C_0805_2012Metric
C9, C10: 10pF; C_0805_2012Metric
C11, C12, C14, C15: 4.7uF; C_0402_1005Metric
C13, C16, C17, C18, C19, C20, C21, C22, C23, C24, C27: 100nF; C_0402_1005Metric
C25, C26: 15p; C_0402_1005Metric
D1: 1N4148W; D_SOD-123
H1, H2, H3, H4: MountingHole; MountingHole_3.5mm_Pad
J1: Conn_01x05_Pin; JST_EH_B5B-EH-A_1x05_P2.50mm_Vertical
J2: UART; JST_SH_BM03B-SRSS-TB_1x03-1MP_P1.00mm_Vertical
J3: RPI SWD; JST_SH_BM03B-SRSS-TB_1x03-1MP_P1.00mm_Vertical
J4: U.FL; U.FL_Molex_MCRF_73412-0110_Vertical
J5: USB_C_Receptacle_USB2.0_16P; USB_C_Receptacle_G-Switch_GT-USB-7051x
J6: GPIO1; IDC-Header_2x06_P2.54mm_Vertical
J7: GPIO2; IDC-Header_2x06_P2.54mm_Vertical
J8: GPIO3; IDC-Header_2x06_P2.54mm_Vertical
JP1: Series; TestPoint_2Pads_Pitch2.54mm_Drill0.8mm
JP2: Parallel 1; TestPoint_2Pads_Pitch2.54mm_Drill0.8mm
JP3: Parallel 2; TestPoint_2Pads_Pitch2.54mm_Drill0.8mm
L1: 3.3uH; L_Murata_DFE201610P
MAIN_SUPPLY1: B2B-PH-K-S; JST_PH_B2B-PH-K_1x02_P2.00mm_Vertical
PMU_STATUS1: WS2812B-2020; LED_WS2812B-2020_PLCC4_2.0x2.0mm
PMU_SUPPLY1: B2B-PH-K-S; JST_PH_B2B-PH-K_1x02_P2.00mm_Vertical
R1, R3, R6: 1k; R_0805_2012Metric
R2: 100; R_0805_2012Metric
R4: 0.1; R_Axial_DIN0414_L11.9mm_D4.5mm_P15.24mm_Horizontal
R5, R9, R10: 10k; R_0805_2012Metric
R7: 20k; R_0805_2012Metric
R8: 8.2k; R_0805_2012Metric
R11, R12, R23: 10k; C_0402_1005Metric
R13: 33; C_0402_1005Metric
R14, R15: 100; C_0402_1005Metric
R16, R17, R21, R22: 1K; C_0402_1005Metric
R18, R19: 27; R_0603_1608Metric
R20: 5.1K; C_0402_1005Metric
RPI_STATUS1: WS2812B-2020; LED_WS2812B-2020_PLCC4_2.0x2.0mm
STM_RESET1: STM_RESET; SW_SPST_EVQP2_MiddlePushTravel_H2.5mm
STM_WAKE1: STM_WAKE; SW_SPST_EVQP2_MiddlePushTravel_H2.5mm
SW1: BOOT; SW_SPST_EVQP2_MiddlePushTravel_H2.5mm
SW2: RESET; SW_SPST_EVQP2_MiddlePushTravel_H2.5mm
TP1: 3V3 TEST; TestPoint_Pad_1.5x1.5mm
TP2: RX_TEST; TestPoint_Pad_1.5x1.5mm
TP3: TX_TEST; TestPoint_Pad_1.5x1.5mm
TP4: MAINS TEST; TestPoint_Pad_1.5x1.5mm
TP5: TAP TEST; TestPoint_Pad_1.5x1.5mm
TP6: PMU SUPPLY TEST; TestPoint_Pad_1.5x1.5mm
U1: Opamp_Quad; TSSOP-14_4.4x5mm_P0.65mm
U2: STM32L031F6P6TR; TSSOP-20_4.4x6.5mm_P0.65mm
U3: MCP1700x-120xxMB; SOT-89-3_Handsoldering
U4: FM24CL16B-GTR; SOIC-8-1EP_3.9x4.9mm_P1.27mm_EP2.29x3mm
U5: NiceRF Lora1262; HOPERF_RFM9XW_SMD
U6: RP2350_80QFN; RP2350-QFN-80-1EP_10x10_P0.4mm_EP3.4x3.4mm_ThermalVias
U7: W25Q16JVSS; SOIC-8_5.3x5.3mm_P1.27mm
U8: MT25QL01GBBB8ESF-0SIT; SOIC-16W-12_7.5x10.3mm_P1.27mm
VR1: TPSM861253RDXR; VREG_TPSM861253RDXR
Y1: Crystal; Crystal_SMD_3215-2Pin_3.2x1.5mm
Y2: ABM8-272-T3; Crystal_SMD_3225-4Pin_3.2x2.5mm
kibuzzard-69F1F93E: G***; kibuzzard-69F1F93E
kibuzzard-69F1F948: G***; kibuzzard-69F1F948
kibuzzard-69F1FA9E: G***; kibuzzard-69F1FA9E
kibuzzard-69F1FABA: G***; kibuzzard-69F1FABA
kibuzzard-69F1FACD, kibuzzard-69F1FACD#2: G***; kibuzzard-69F1FACD
kibuzzard-69F1FAE9: G***; kibuzzard-69F1FAE9
kibuzzard-69F1FB2A, kibuzzard-69F1FB2A#2: G***; kibuzzard-69F1FB2A
kibuzzard-69F1FB3C: G***; kibuzzard-69F1FB3C
kibuzzard-69F1FB5C: G***; kibuzzard-69F1FB5C
kibuzzard-69F1FB6D: G***; kibuzzard-69F1FB6D
kibuzzard-69F1FB08: G***; kibuzzard-69F1FB08
kibuzzard-69F1FB43: G***; kibuzzard-69F1FB43
kibuzzard-69F1FBEC: G***; kibuzzard-69F1FBEC
kibuzzard-69F1FC5E: G***; kibuzzard-69F1FC5E
kibuzzard-69F15CED: G***; kibuzzard-69F15CED
kibuzzard-69F15D5F, kibuzzard-69F15D5F#2: G***; kibuzzard-69F15D5F
kibuzzard-69F15D28: G***; kibuzzard-69F15D28
kibuzzard-69F15D48, kibuzzard-69F15D48#2: G***; kibuzzard-69F15D48
kibuzzard-69F15DA2: G***; kibuzzard-69F15DA2
kibuzzard-69F20A0D: G***; kibuzzard-69F20A0D
kibuzzard-69F20A1A: G***; kibuzzard-69F20A1A
kibuzzard-69F204CF: G***; kibuzzard-69F204CF
kibuzzard-69F204DC: G***; kibuzzard-69F204DC
kibuzzard-69F209F9: G***; kibuzzard-69F209F9

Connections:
+1V1: C12.1, C13.1, C15.1, C16.1, L1.1, U6.10 (DVDD), U6.32 (DVDD), U6.51 (DVDD), U6.65 (VREG_FB)
+3V3: C1.1, C2.1, C11.1, C17.1, C18.1, C19.1, C20.1, C21.1, C22.1, C23.1, C24.1, C27.1, J6.1, J7.1, J8.1, R11.2, R12.2, R13.1, R23.1, RPI_STATUS1.4 (VDD), TP1.1, U1.4 (V+), U5.13 (3.3V), U6.5 (IOVDD), U6.15 (IOVDD), U6.24 (IOVDD), U6.29 (IOVDD), U6.41 (IOVDD), U6.50 (IOVDD), U6.59 (ADC_AVDD), U6.60 (IOVDD), U6.64 (VREG_VIN), U6.68 (USB_OTP_VDD), U6.69 (QSPI_IOVDD), U6.76 (IOVDD), U7.8 (VCC), U8.2 (VCC), VR1.3 (VOUT), VR1.7 (VOS)
+9V: J6.2, J7.2, J8.2, JP2.1 (A), MAIN_SUPPLY1.1, R7.2, TP4.1, VR1.1 (VIN)
/pmu/3V3_POWER_ON: U2.7 (PA1), VR1.6 (EN)
/pmu/MEAS_CURRENT: R6.1, U2.13 (PA7)
/pmu/MEAS_V: U1.6 (-), U1.7, U2.12 (PA6)
/pmu/NRST: C8.2, J1.4, STM_RESET1.1, U2.4 (NRST)
/pmu/SCL: U2.17 (PA9), U4.6 (SCL)
/pmu/SDA: U2.18 (PA10), U4.5 (SDA)
/rp2350B (page 4)/D+: J5.A6 (D+), J5.B6 (D+), R18.2
/rp2350B (page 4)/D-: J5.A7 (D-), J5.B7 (D-), R19.2
/rp2350B (page 4)/GPIO20: J8.9, U6.20 (GPIO20)
/rp2350B (page 4)/GPIO21: J8.10, U6.21 (GPIO21)
/rp2350B (page 4)/GPIO22: J8.7, U6.22 (GPIO22)
/rp2350B (page 4)/GPIO23: J8.8, U6.23 (GPIO23)
/rp2350B (page 4)/GPIO24: J8.5, U6.25 (GPIO24)
/rp2350B (page 4)/GPIO25: J8.6, U6.26 (GPIO25)
/rp2350B (page 4)/GPIO26: J8.3, U6.27 (GPIO26)
/rp2350B (page 4)/GPIO27: J8.4, U6.28 (GPIO27)
/rp2350B (page 4)/GPIO28: J7.10, U6.45 (GPIO36)
/rp2350B (page 4)/GPIO29: J7.9, U6.46 (GPIO37)
/rp2350B (page 4)/GPIO30: J7.8, U6.47 (GPIO38)
/rp2350B (page 4)/GPIO31: J7.7, U6.48 (GPIO39)
/rp2350B (page 4)/GPIO40_ADC0: J7.6, U6.49 (GPIO40_ADC0)
/rp2350B (page 4)/GPIO41_ADC1: J7.5, U6.52 (GPIO41_ADC1)
/rp2350B (page 4)/GPIO42_ADC2: J7.4, U6.53 (GPIO42_ADC2)
/rp2350B (page 4)/GPIO43_ADC3: J7.3, U6.54 (GPIO43_ADC3)
/rp2350B (page 4)/MISO: U5.2 (MISO), U6.11 (GPIO12)
/rp2350B (page 4)/MOSI: U5.3 (MOSI), U6.14 (GPIO15)
/rp2350B (page 4)/MOTOR_HI_1: J6.10, U6.36 (GPIO28)
/rp2350B (page 4)/MOTOR_HI_2: J6.8, U6.38 (GPIO30)
/rp2350B (page 4)/MOTOR_LO_1: J6.6, U6.40 (GPIO32)
/rp2350B (page 4)/MOTOR_LO_2: J6.4, U6.43 (GPIO34)
/rp2350B (page 4)/MT25_CS: U6.78 (GPIO1), U8.7 (S#)
/rp2350B (page 4)/MT25_MISO: U6.77 (GPIO0), U8.8 (DQ1)
/rp2350B (page 4)/MT25_MOSI: U6.80 (GPIO3), U8.15 (DQ0)
/rp2350B (page 4)/MT25_RESET: U6.2 (GPIO5), U8.3 (RESET#)
/rp2350B (page 4)/MT25_SCK: U6.79 (GPIO2), U8.16 (C)
/rp2350B (page 4)/QSPI_D0: U6.72 (QSPI_SD0), U7.5 (DI/IO_{0})
/rp2350B (page 4)/QSPI_D1: U6.74 (QSPI_SD1), U7.2 (DO/IO_{1})
/rp2350B (page 4)/QSPI_D2: U6.73 (QSPI_SD2), U7.3 (~WP/IO_{2})
/rp2350B (page 4)/QSPI_D3: U6.70 (QSPI_SD3), U7.7 (~HOLD/~RESET/IO_{3})
/rp2350B (page 4)/QSPI_SCK: U6.71 (QSPI_SCLK), U7.6 (CLK)
/rp2350B (page 4)/QSPI_SS: R16.1, R23.2, U6.75 (QSPI_SS), U7.1 (~CS)
/rp2350B (page 4)/RFM_BUSY: U5.16 (BUSY), U6.18 (GPIO18)
/rp2350B (page 4)/RFM_CS: R12.1, U5.5 (NSS), U6.8 (GPIO10)
/rp2350B (page 4)/RFM_IO1: U5.15 (DIO1), U6.19 (GPIO19)
/rp2350B (page 4)/RFM_RST: R11.1, U5.6 (RESET), U6.16 (GPIO16)
/rp2350B (page 4)/RGB_LED: RPI_STATUS1.3 (DIN), U6.1 (GPIO4)
/rp2350B (page 4)/RUN: SW2.1, U6.35 (RUN)
/rp2350B (page 4)/RX: TP3.1, U2.8 (PA2), U6.7 (GPIO9)
/rp2350B (page 4)/SCK: U5.4 (SCK), U6.13 (GPIO14)
/rp2350B (page 4)/TX: TP2.1, U2.9 (PA3), U6.6 (GPIO8)
/rp2350B (page 4)/USBBOOT: D1.1 (K), SW1.1
/rp2350B (page 4)/VALVE_1: J6.9, U6.37 (GPIO29)
/rp2350B (page 4)/VALVE_2: J6.7, U6.39 (GPIO31)
/rp2350B (page 4)/VALVE_3: J6.3, U6.44 (GPIO35)
/rp2350B (page 4)/VALVE_4: J6.5, U6.42 (GPIO33)
/rp2350B (page 4)/VREG_AVDD: C14.1, R13.2, U6.61 (VREG_AVDD)
/rp2350B (page 4)/VREG_LX: L1.2, U6.63 (VREG_LX)
/rp2350B (page 4)/XIN: C25.1, U6.30 (XIN), Y2.1
/rp2350B (page 4)/XOUT: R22.2, U6.31 (XOUT)
GND: C1.2, C2.2, C3.2, C4.2, C5.2, C6.1, C7.1, C8.1, C9.2, C10.2, C11.2, C12.2, C13.2, C14.2, C15.2, C16.2, C17.2, C18.2, C19.2, C20.2, C21.2, C22.2, C23.2, C24.2, C25.2, C26.2, C27.2, J1.5, J2.2, J3.2, J4.2 (Ext), J5.A1 (GND), J5.A12 (GND), J5.B1 (GND), J5.B12 (GND), J5.S1 (SHIELD), J6.12, J7.12, J8.12, PMU_STATUS1.2 (VSS), R2.2, R3.1, R4.1, R8.1, R9.1, R10.2, R17.1, R20.2, R21.2, RPI_STATUS1.2 (VSS), STM_RESET1.2, SW1.2, U1.11 (V-), U2.15 (VSS), U3.1 (GND), U4.4 (GND), U4.7 (WP), U5.1 (GND), U5.8 (GND), U5.10 (GND), U6.62 (VREG_PGND), U6.81 (GND), U7.4 (GND), U8.10 (VSS), VR1.4 (PGND), Y2.2, Y2.4
GNDPWR: JP3.2 (B), PMU_SUPPLY1.2, R1.2, R4.2
unnamed: C26.1, R22.1, Y2.3
unnamed: D1.2 (A), R16.2
unnamed: J1.2, J2.1, U2.20 (PA14)
unnamed: J1.3, J2.3, U2.19 (PA13)
unnamed: J3.1, R14.1
unnamed: J3.3, R15.1
unnamed: J4.1 (In), U5.9 (ANT)
unnamed: J5.A5 (CC1), R21.1
unnamed: J5.B5 (CC2), R20.1
unnamed: JP1.1 (A), JP3.1 (A), MAIN_SUPPLY1.2
unnamed: C6.2, JP1.2 (B), JP2.2 (B), PMU_SUPPLY1.1, TP5.1, U3.2 (VI)
unnamed: PMU_STATUS1.3 (DIN), U2.11 (PA5)
unnamed: R5.2, R6.2, U1.1
unnamed: R9.2, STM_WAKE1.1
unnamed: R17.2, SW2.2
unnamed: R1.1, R2.1, U1.3 (+)
unnamed: R3.2, R5.1, U1.2 (-)
unnamed: R7.1, R8.2, U1.5 (+)
unnamed: STM_WAKE1.2, U2.6 (PA0-CK_IN)
unnamed: R10.1, U2.1 (PB9-BOOT0)
unnamed: C9.1, C10.1, U2.2 (PC14-OSC32_IN), U2.3 (PC15-OSC32_OUT), Y1.1, Y1.2
unnamed: R14.2, U6.33 (SWCLK)
unnamed: R15.2, U6.34 (SWD)
unnamed: R19.1, U6.66 (USB_DM)
unnamed: R18.1, U6.67 (USB_DP)
VBUS: J5.A4 (VBUS), J5.A9 (VBUS), J5.B4 (VBUS), J5.B9 (VBUS), U6.3 (GPIO6)
VDD: C3.1, C4.1, C5.1, C7.2, J1.1, J6.11, J7.11, J8.11, PMU_STATUS1.4 (VDD), TP6.1, U2.5 (VDDA), U2.16 (VDD), U3.3 (VO), U4.8 (VCC)

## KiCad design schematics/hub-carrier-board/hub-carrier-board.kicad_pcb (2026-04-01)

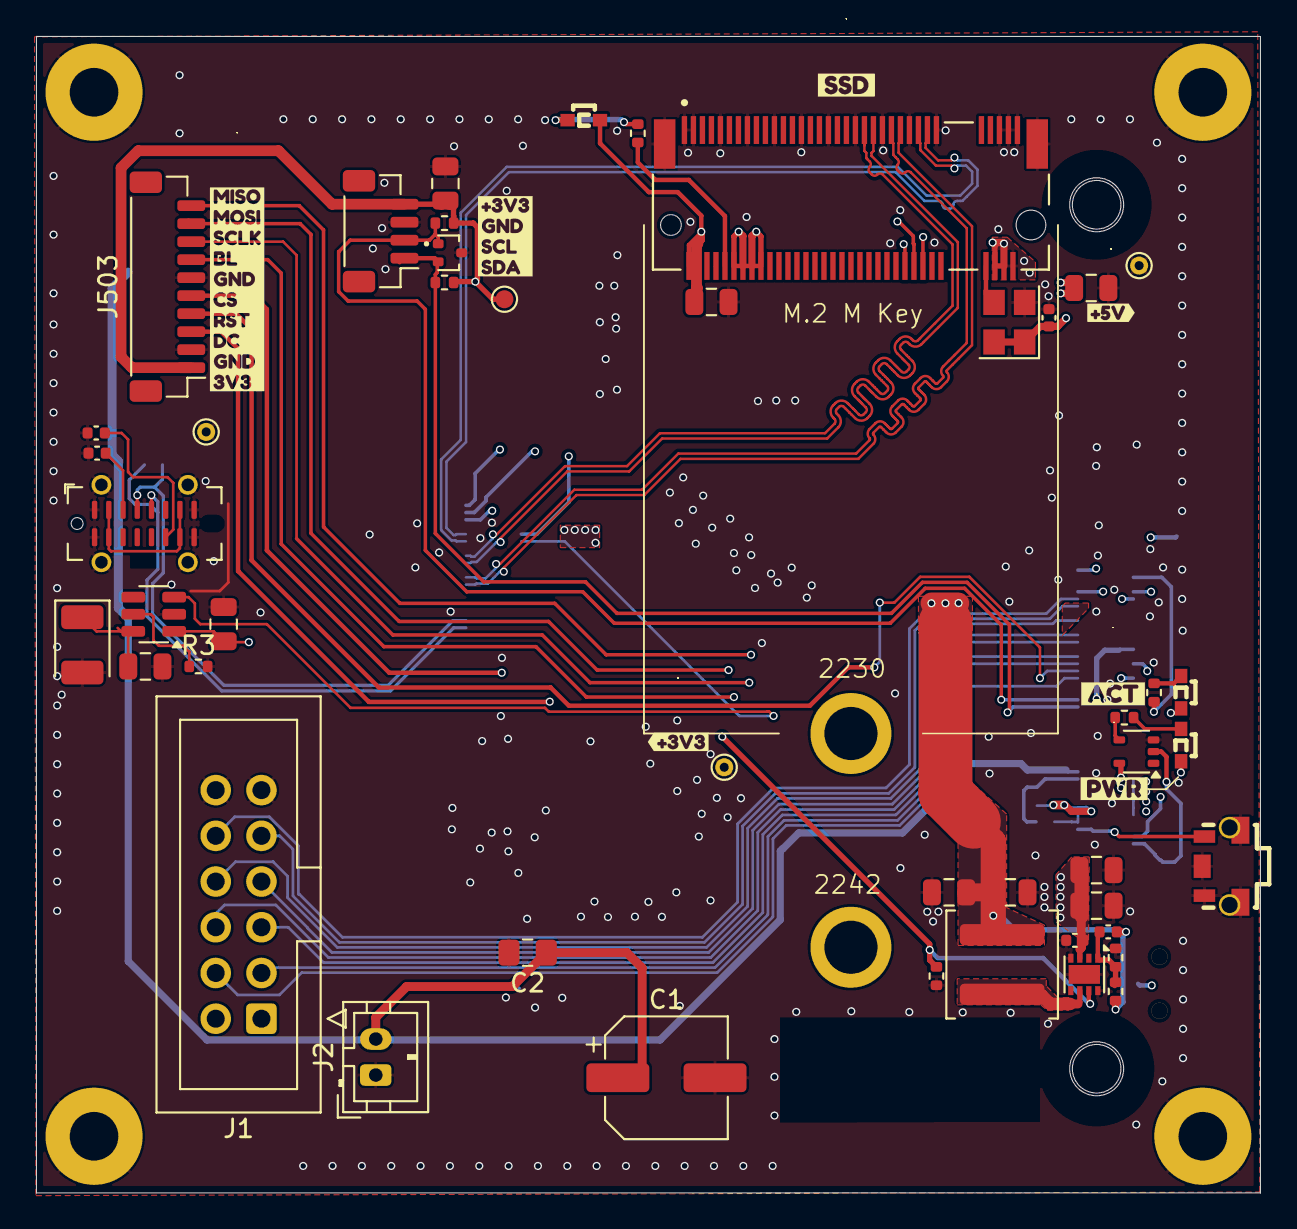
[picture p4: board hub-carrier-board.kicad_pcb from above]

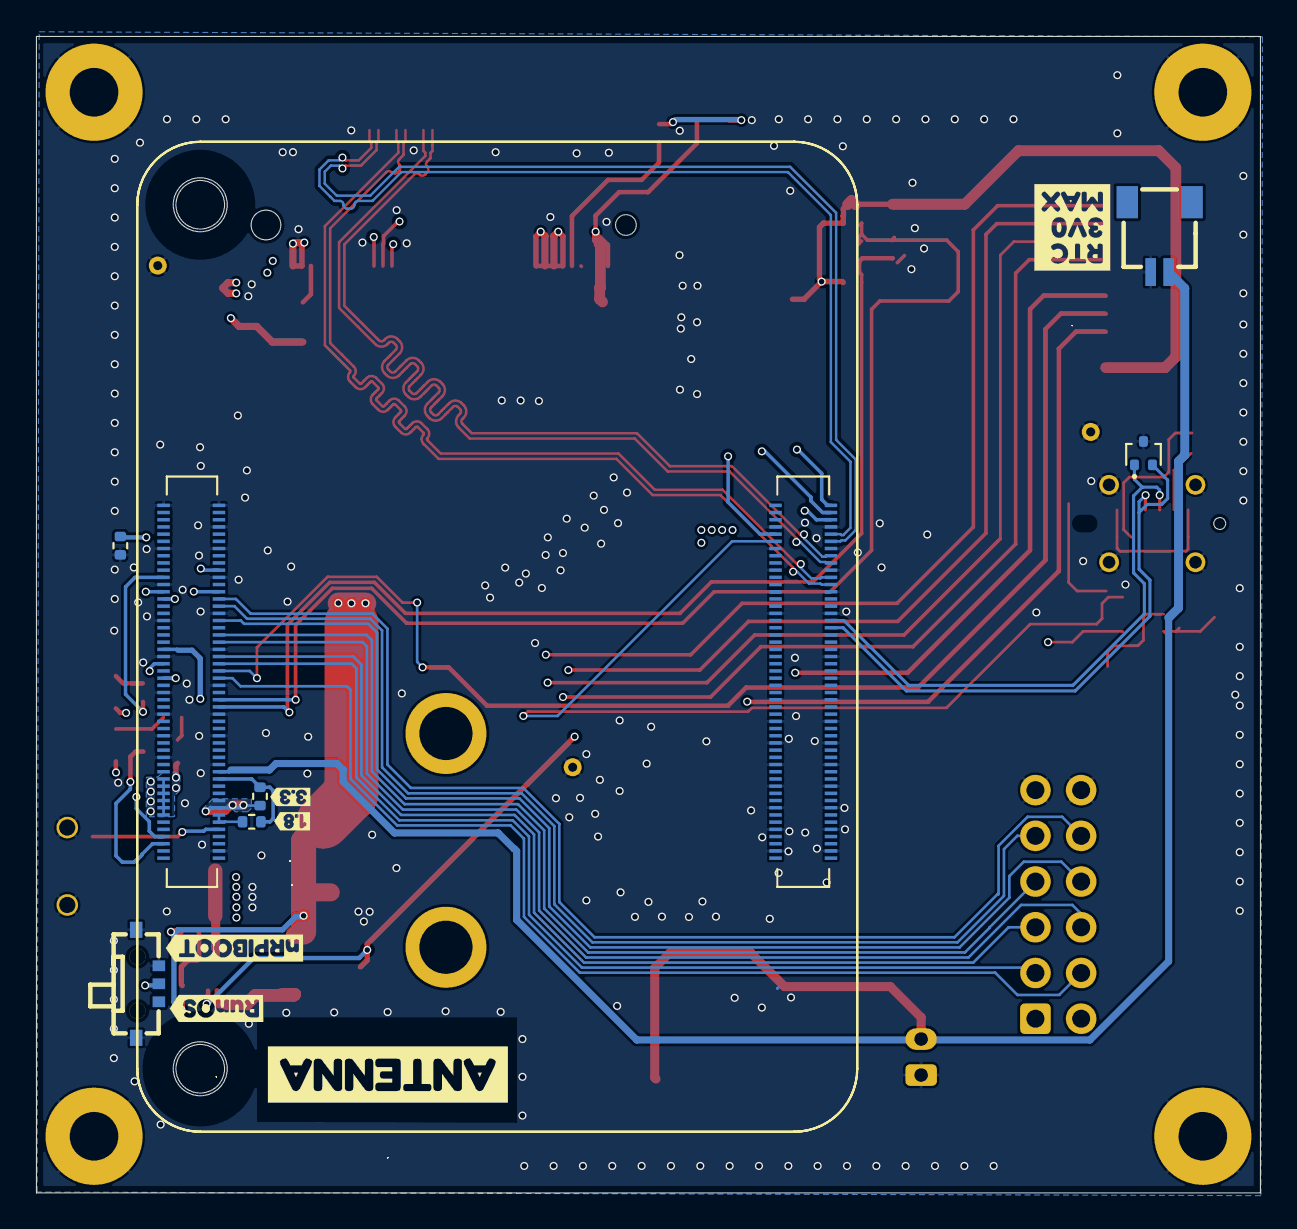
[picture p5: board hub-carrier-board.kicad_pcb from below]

Board: 4 copper layers, 68.0 x 64.2 mm, 73 parts (14 on the bottom side), 56 nets.

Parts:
C1: 470; CP_Elec_6.3x7.7
C2: 100nF; C_0805_2012Metric_Pad1.18x1.45mm_HandSolder
C601: 4u7; C_0805_2012Metric
C701, C703, C704, C705, C708, C709, C710, C711: 10u; C_0805_2012Metric
C702: 100uF; CP_EIA-3528-21_Kemet-B
C706, C712: 100n; C_0402_1005Metric
C707: 4.7nF; C_0402_1005Metric
CN1: SM02B-SRSS-TB (LF)(SN); CONN-SMD_2P-P1.00_SM02B-SRSS-TB-LF-SN
D502, D701: RCLAMP0502BA; SOT-416
D605, D606, D702: GREEN; LED-SMD_L1.7-W0.6-RD
H102, H103, H104, H105: MountingHole_Pad; MountingHole_2.7mm_Pad
J1: GPIO1; IDC-Header_2x06_P2.54mm_Vertical
J2: PWR; JST_PH_B2B-PH-K_1x02_P2.00mm_Vertical
J5: USB_C_Receptacle_USB2.0_16P; USB_C_Receptacle_G-Switch_GT-USB-7051x
J101: ComputeModule5-CM5; Raspberry-Pi-5-Compute-Module_GPIO
J102: ComputeModule5-CM5; Raspberry-Pi-5-Compute-Module_HSS
J502: I2C; JST_SH_BM04B-SRSS-TB_1x04-1MP_P1.00mm_Vertical
J503: SPI; JST_SH_BM10B-SRSS-TB_1x10-1MP_P1.00mm_Vertical
J701: Bus_M.2_Socket_M; M.2 M Key socket_2230_2242
L701: 2.2uH; L_Coilcraft_XAL5030-XXX
M701, M702: M.2 Solder Nut; MountingHole_3mm_Pad
R3: 15k; R_0402_1005Metric
R20, R21: 5.1K; C_0402_1005Metric
R102, R103: 0R; R_0402_1005Metric
R104, R705: 10k; R_0402_1005Metric
R501, R502, R605, R606, R706, R707: 2k2; R_0402_1005Metric
R704: 100k; R_0402_1005Metric
SW101: MK-11C04-G013; SW-SMD_MK-11C04-G013
SW501: TS-1010A-B; SW-SMD_TS-1010A-B
TP103: +3V3_PI; TestPoint_Pad_D1.0mm
TP104, TP105, TP106: GND; TestPoint_THTPad_D1.0mm_Drill0.5mm
U602: SN74LVC1G14DBVR; SOT-353_SC-70-5
U701: AP22653W6; SOT-23-6
U702: AP3441SHE-7B; DFN-8-1EP_2x2mm_P0.5mm_EP1.05x1.75mm
U703: ASEK-32.768KHZ-L-R-T; Crystal_SMD_3225-4Pin_3.2x2.5mm
kibuzzard-67CC6BD3: G***; kibuzzard-67CC6BD3
kibuzzard-67CC6D9E: G***; kibuzzard-67CC6D9E
kibuzzard-67CC6D94: G***; kibuzzard-67CC6D94
kibuzzard-67CC7445: G***; kibuzzard-67CC7445
kibuzzard-67EBAC4C: G***; kibuzzard-67EBAC4C
kibuzzard-67EBB9C1: G***; kibuzzard-67EBB9C1
kibuzzard-67EBF0A0: G***; kibuzzard-67EBF0A0
kibuzzard-69AD8816: G***; kibuzzard-69AD8816
kibuzzard-6773B9CA: G***; kibuzzard-6773B9CA
kibuzzard-6773B9F7: G***; kibuzzard-6773B9F7
kibuzzard-6773BA89: G***; kibuzzard-6773BA89
kibuzzard-6773C376: G***; kibuzzard-6773C376
kibuzzard-67795592: G***; kibuzzard-67795592

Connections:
+1V8: J101.88 (+1.8v_(Output)), J101.90 (+1.8v_(Output)), R103.1
+3V3_PI: C601.1, J101.84 (+3.3v_(Output)), J101.86 (+3.3v_(Output)), J502.4, J503.1, R102.1, R501.1, R502.1, TP103.1
+5V: C1.1, C2.1, C701.1, C704.1, C705.1, C706.1, D605.2 (A), D606.2 (A), J2.2, U602.5 (VCC), U701.1 (IN), U702.3 (VIN)
+BATT: CN1.1, J101.76 (VBAT)
/CM5/+5V: J101.77 (+5v_(Input)), J101.79 (+5v_(Input)), J101.81 (+5v_(Input)), J101.83 (+5v_(Input)), J101.85 (+5v_(Input)), J101.87 (+5v_(Input))
/CM5/BL_GPIO24: J101.45 (GPIO24), J503.7
/CM5/CS_GPIO18: J101.49 (GPIO18), J503.5
/CM5/DC_GPI25: J101.41 (GPIO25), J503.3
/CM5/EEPROM_nWP: J101.20 (EEPROM_nWP), R104.2
/CM5/GPIO_VREF: J101.78 (GPIO_VREF(1.8v/3.3v_Input)), R102.2, R103.2
/CM5/MISO_GPIO19: J101.26 (GPIO19), J503.10
/CM5/MOSI_GPIO20: J101.27 (GPIO20), J503.9
/CM5/PCIE_PI.CLK_N: J102.112 (PCIe_CLK_N), J701.53 (REFCLKn)
/CM5/PCIE_PI.CLK_P: J102.110 (PCIe_CLK_P), J701.55 (REFCLKp)
/CM5/PCIE_PI.PWR_EN: J102.106 (PCIE_PWR_EN), R704.1, U702.7 (EN)
/CM5/PCIE_PI.RX_N: J102.118 (PCIe_RX_N), J701.43 (PETp0)
/CM5/PCIE_PI.RX_P: J102.116 (PCIe_RX_P), J701.41 (PETn0)
/CM5/PCIE_PI.TX_N: J102.124 (PCIe_TX_N), J701.49 (PERp0)
/CM5/PCIE_PI.TX_P: J102.122 (PCIe_TX_P), J701.47 (PERn0)
/CM5/PCIE_PI.nCLKREQ: J102.102 (PCIe_nCLKREQ), J701.52 (~CLKREQ)
/CM5/PCIE_PI.nRST: J102.109 (PCIe_nRST), J701.50 (~PERST)
/CM5/PCIE_PI.nWAKE: J102.104 (PCIE_nWAKE), J701.54 (~PEWAKE)
/CM5/PI_nLED_PWR: J101.95 (LED_nPWR), U602.2
/CM5/PWR_BUT: J101.92 (PWR_BUT), SW501.1
/CM5/RST_GPIO27: J101.48 (GPIO27), J503.4
/CM5/SCL1_IO3: D502.1 (K1), J101.56 (GPIO3), J502.2, R502.2
/CM5/SCLK_GPIO21: J101.25 (GPIO21), J503.8
/CM5/SDA1_IO2: D502.2 (K2), J101.58 (GPIO2), J502.1, R501.2
/CM5/VBUS_EN: J102.111 (VBUS_EN), U701.3 (EN)
/CM5/nLED_ACTIVITY: J101.21 (LED_nACT), R606.2
/CM5/nRPIBOOT: J101.93 (nRPIBOOT), SW101.C
/PCIe-M2/FB: C707.2, R705.2, R706.1, U702.1 (FB)
/PCIe-M2/M2_LX: L701.1, U702.6 (LX)
D+: D701.1 (K1), J5.A6 (D+), J102.134 (USB3-0-D_P)
D-: D701.2 (K2), J5.A7 (D-), J102.136 (USB3-0-D_N)
GND: C1.2, C2.2, C601.2, C701.2, C702.2, C703.2, C704.2, C705.2, C706.2, C708.2, C709.2, C710.2, C711.2, C712.2, CN1.2, D502.3 (A), D701.3 (A), H102.1, H103.1, H104.1, H105.1, J1.11, J1.12, J2.1, J5.A1 (GND), J5.A12 (GND), J5.B1 (GND), J5.B12 (GND), J5.S1 (SHIELD), J101.1 (GND), J101.2 (GND), J101.8 (GND), J101.13 (GND), J101.14 (GND), J101.22 (GND), J101.23 (GND), J101.32 (GND), J101.33 (GND), J101.42 (GND), J101.43 (GND), J101.52 (GND), J101.53 (GND), J101.59 (GND), J101.60 (GND), J101.65 (GND), J101.66 (GND), J101.71 (GND), J101.74 (GND), J101.98 (GND), J102.107 (GND), J102.108 (GND), J102.113 (GND), J102.114 (GND), J102.119 (GND), J102.120 (GND), J102.125 (GND), J102.126 (GND), J102.131 (GND), J102.132 (GND), J102.137 (GND), J102.138 (GND), J102.144 (GND), J102.150 (GND), J102.155 (GND), J102.156 (GND), J102.161 (GND), J102.162 (GND), J102.167 (GND), J102.168 (GND), J102.173 (GND), J102.174 (GND), J102.179 (GND), J102.180 (GND), J102.185 (GND), J102.186 (GND), J102.191 (GND), J102.192 (GND), J102.197 (GND), J102.198 (GND), J502.3, J503.2, J503.6, J701.1 (GND), J701.3 (GND), J701.9 (GND), J701.15 (GND), J701.21 (GND), J701.27 (GND), J701.33 (GND), J701.39 (GND), J701.45 (GND), J701.51 (GND), J701.57 (GND), J701.71 (GND), J701.73 (GND), J701.75 (GND), J701.S1, J701.S2, R3.2, R20.2, R21.2, R104.1, R704.2, R706.2, SW101.1, SW101.4, SW101.5, SW501.2, SW501.3, SW501.4, SW501.5, TP104.1, TP105.1, TP106.1, U602.3 (GND), U701.2 (GND), U702.4 (PGND), U702.8 (SGND), U702.9 (PAD), U703.2 (GND)
GPIO5: J1.8, J101.34 (GPIO5)
GPIO6: J1.9, J101.30 (GPIO6)
GPIO9: J1.6, J101.40 (GPIO9)
GPIO10: J1.5, J101.44 (GPIO10)
GPIO11: J1.7, J101.38 (GPIO11)
GPIO13: J1.10, J101.28 (GPIO13)
GPIO17: J1.4, J101.50 (GPIO17)
GPIO22: J1.3, J101.46 (GPIO22)
M2_3V3: C707.1, C708.1, C709.1, C710.1, C711.1, C712.1, D702.2 (A), J701.2 (3.3V), J701.4 (3.3V), J701.12 (3.3V), J701.14 (3.3V), J701.16 (3.3V), J701.18 (3.3V), J701.70 (3.3V), J701.72 (3.3V), J701.74 (3.3V), L701.2, R705.1, U703.1 (EN), U703.4 (VDD)
unnamed: D605.1 (K), R605.1
unnamed: D606.1 (K), R606.1
unnamed: D702.1 (K), R707.1
unnamed: J5.A5 (CC1), R21.1
unnamed: J5.B5 (CC2), R20.1
unnamed: J701.10 (DAS/~DSS/~LED1), R707.2
unnamed: J701.68 (SUSCLK), U703.3 (Out)
unnamed: R605.2, U602.4
unnamed: R3.1, U701.5 (ILIM)
VBUS: J5.A4 (VBUS), J5.A9 (VBUS), J5.B4 (VBUS), J5.B9 (VBUS)
VBUS_USB2.0: C702.1, C703.1, U701.6 (OUT)

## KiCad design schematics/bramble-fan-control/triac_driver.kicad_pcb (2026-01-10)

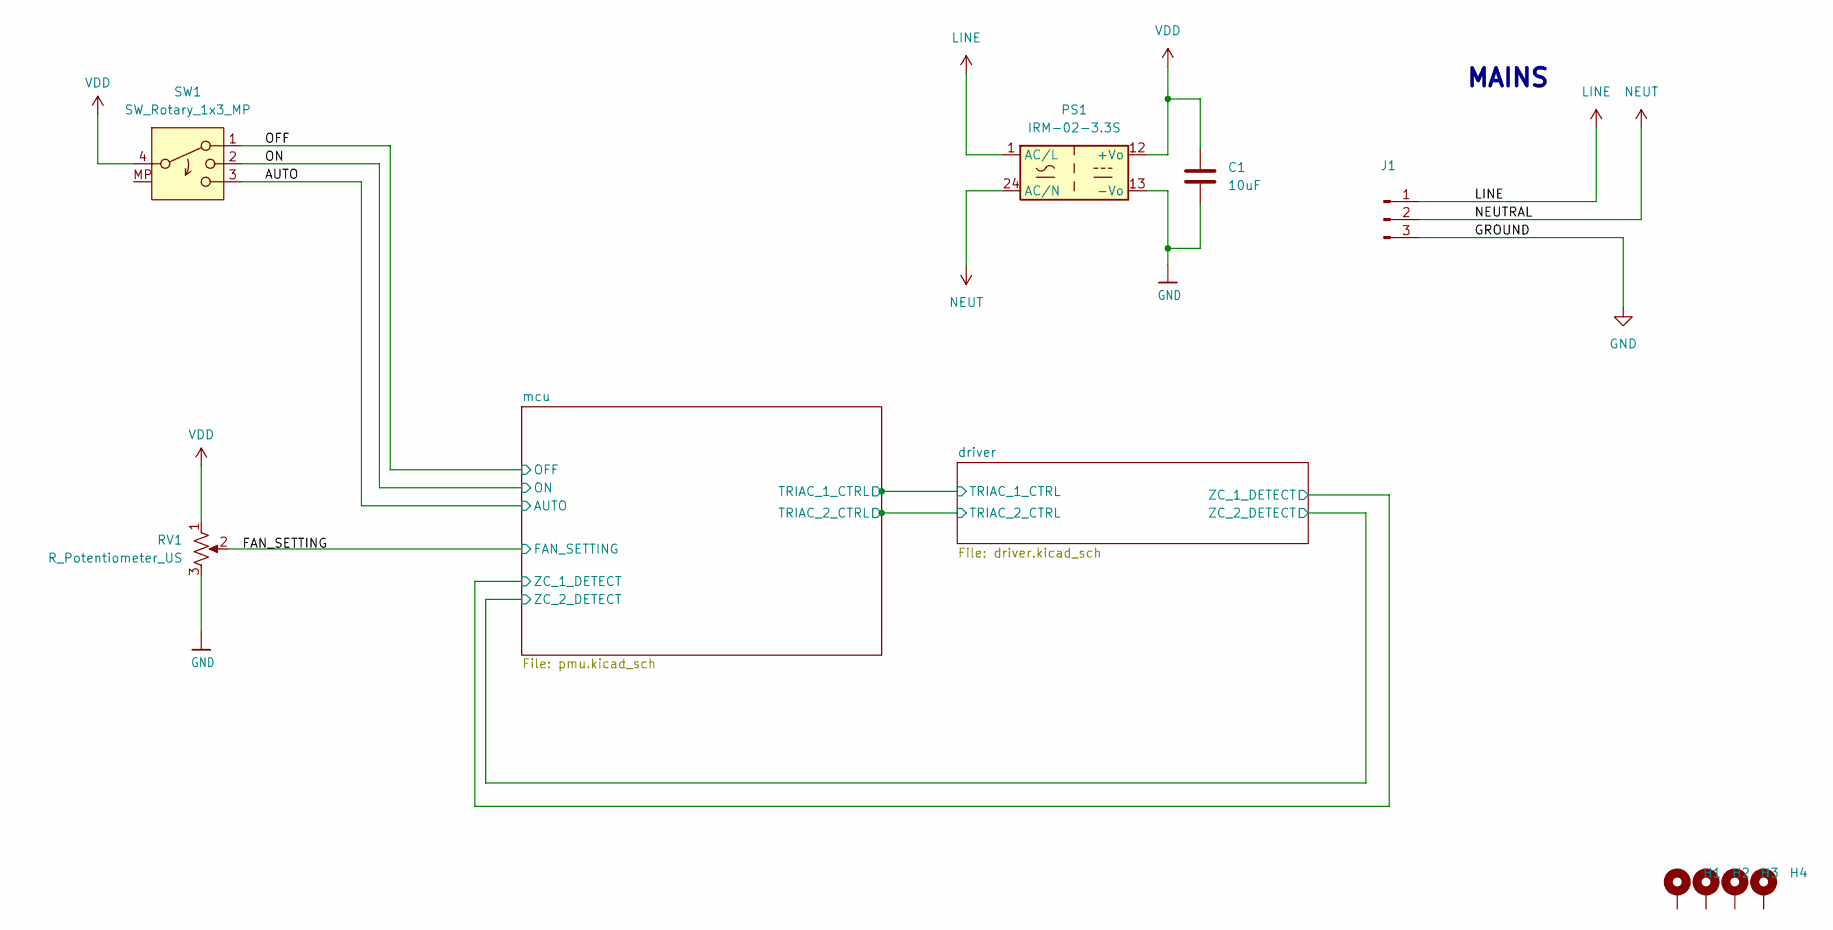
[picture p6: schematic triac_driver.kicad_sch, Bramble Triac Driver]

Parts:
C1: 10uF; C_0805_2012Metric
H1, H2, H3, H4: MountingHole_Pad; MountingHole_2.5mm_Pad
J1: Conn_01x03_Pin; TerminalBlock_Phoenix_MKDS-1,5-3-5.08_1x03_P5.08mm_Horizont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
PS1: IRM-02-3.3S; Converter_ACDC_MeanWell_IRM-02-xx_SMD
RV1: R_Potentiometer_US; PinHeader_1x03_P2.54mm_Horizontal
SW1: SW_Rotary_1x3_MP; PinHeader_1x03_P2.54mm_Vertical

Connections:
/AUTO: SW1.3; also elsewhere on the board
/OFF: SW1.1; also elsewhere on the board
/ON: SW1.2; also elsewhere on the board
/mcu/FAN_SETTING: RV1.2; also elsewhere on the board
GND: C1.2, J1.3, PS1.13 (-Vo), RV1.3; also elsewhere on the board
LINE: J1.1, PS1.1 (AC/L); also elsewhere on the board
NEUT: J1.2, PS1.24 (AC/N)
VDD: C1.1, PS1.12 (+Vo), RV1.1, SW1.4; also elsewhere on the board

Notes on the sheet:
MAINS

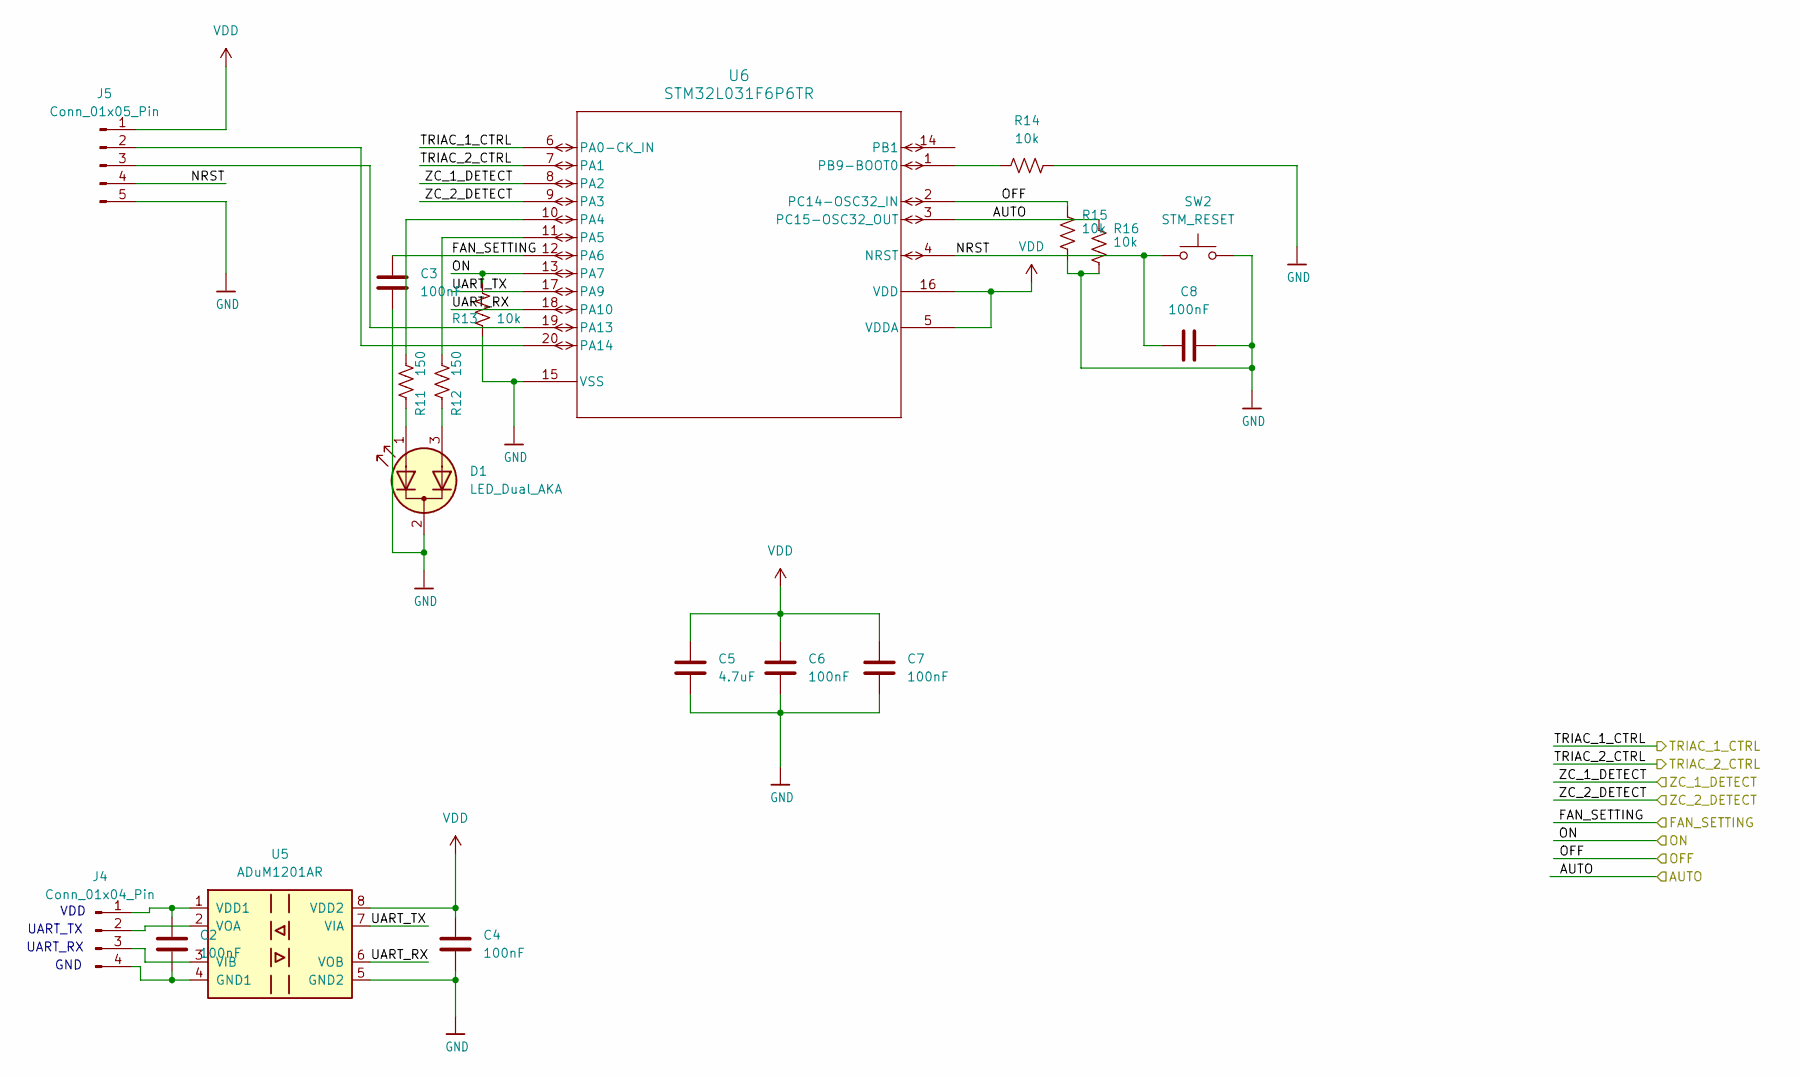
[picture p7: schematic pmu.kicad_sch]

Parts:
C2, C3, C4, C6, C7, C8: 100nF; C_0805_2012Metric
C5: 4.7uF; C_0805_2012Metric
D1: LED_Dual_AKA; LED_D3.0mm-3
J4: Conn_01x04_Pin; PinHeader_1x04_P2.54mm_Vertical
J5: Conn_01x05_Pin; JST_EH_B5B-EH-A_1x05_P2.50mm_Vertical
R11, R12: 150; R_0805_2012Metric
R13, R14, R15, R16: 10k; R_0805_2012Metric
SW2: STM_RESET; SW_SPST_EVQP2_MiddlePushTravel_H2.5mm
U5: ADuM1201AR; SOIC-8_3.9x4.9mm_P1.27mm
U6: STM32L031F6P6TR; TSSOP-20_4.4x6.5mm_P0.65mm

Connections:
/AUTO: R16.1, U6.3 (PC15-OSC32_OUT); also elsewhere on the board
/OFF: R15.1, U6.2 (PC14-OSC32_IN); also elsewhere on the board
/ON: R13.1, U6.13 (PA7); also elsewhere on the board
/mcu/FAN_SETTING: C3.1, U6.12 (PA6); also elsewhere on the board
/mcu/NRST: C8.2, J5.4, SW2.1, U6.4 (NRST)
/mcu/TRIAC_1_CTRL: U6.6 (PA0-CK_IN); also elsewhere on the board
/mcu/TRIAC_2_CTRL: U6.7 (PA1); also elsewhere on the board
/mcu/UART_RX: U5.6 (VOB), U6.18 (PA10)
/mcu/UART_TX: U5.7 (VIA), U6.17 (PA9)
/mcu/ZC_1_DETECT: U6.8 (PA2); also elsewhere on the board
/mcu/ZC_2_DETECT: U6.9 (PA3); also elsewhere on the board
GND: C3.2, C4.2, C5.2, C6.2, C7.2, C8.1, D1.2 (K), J5.5, R13.2, R14.2, R15.2, R16.2, SW2.2, U5.5 (GND2), U6.15 (VSS); also elsewhere on the board
unnamed: D1.1 (A1), R11.1
unnamed: D1.3 (A2), R12.1
unnamed: C2.1, J4.1, U5.1 (VDD1)
unnamed: J4.2, U5.2 (VOA)
unnamed: J4.3, U5.3 (VIB)
unnamed: C2.2, J4.4, U5.4 (GND1)
unnamed: J5.2, U6.20 (PA14)
unnamed: J5.3, U6.19 (PA13)
unnamed: R11.2, U6.10 (PA4)
unnamed: R12.2, U6.11 (PA5)
unnamed: R14.1, U6.1 (PB9-BOOT0)
VDD: C4.1, C5.1, C6.1, C7.1, J5.1, U5.8 (VDD2), U6.5 (VDDA), U6.16 (VDD); also elsewhere on the board

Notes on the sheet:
GND
UART_RX
VDD
UART_TX

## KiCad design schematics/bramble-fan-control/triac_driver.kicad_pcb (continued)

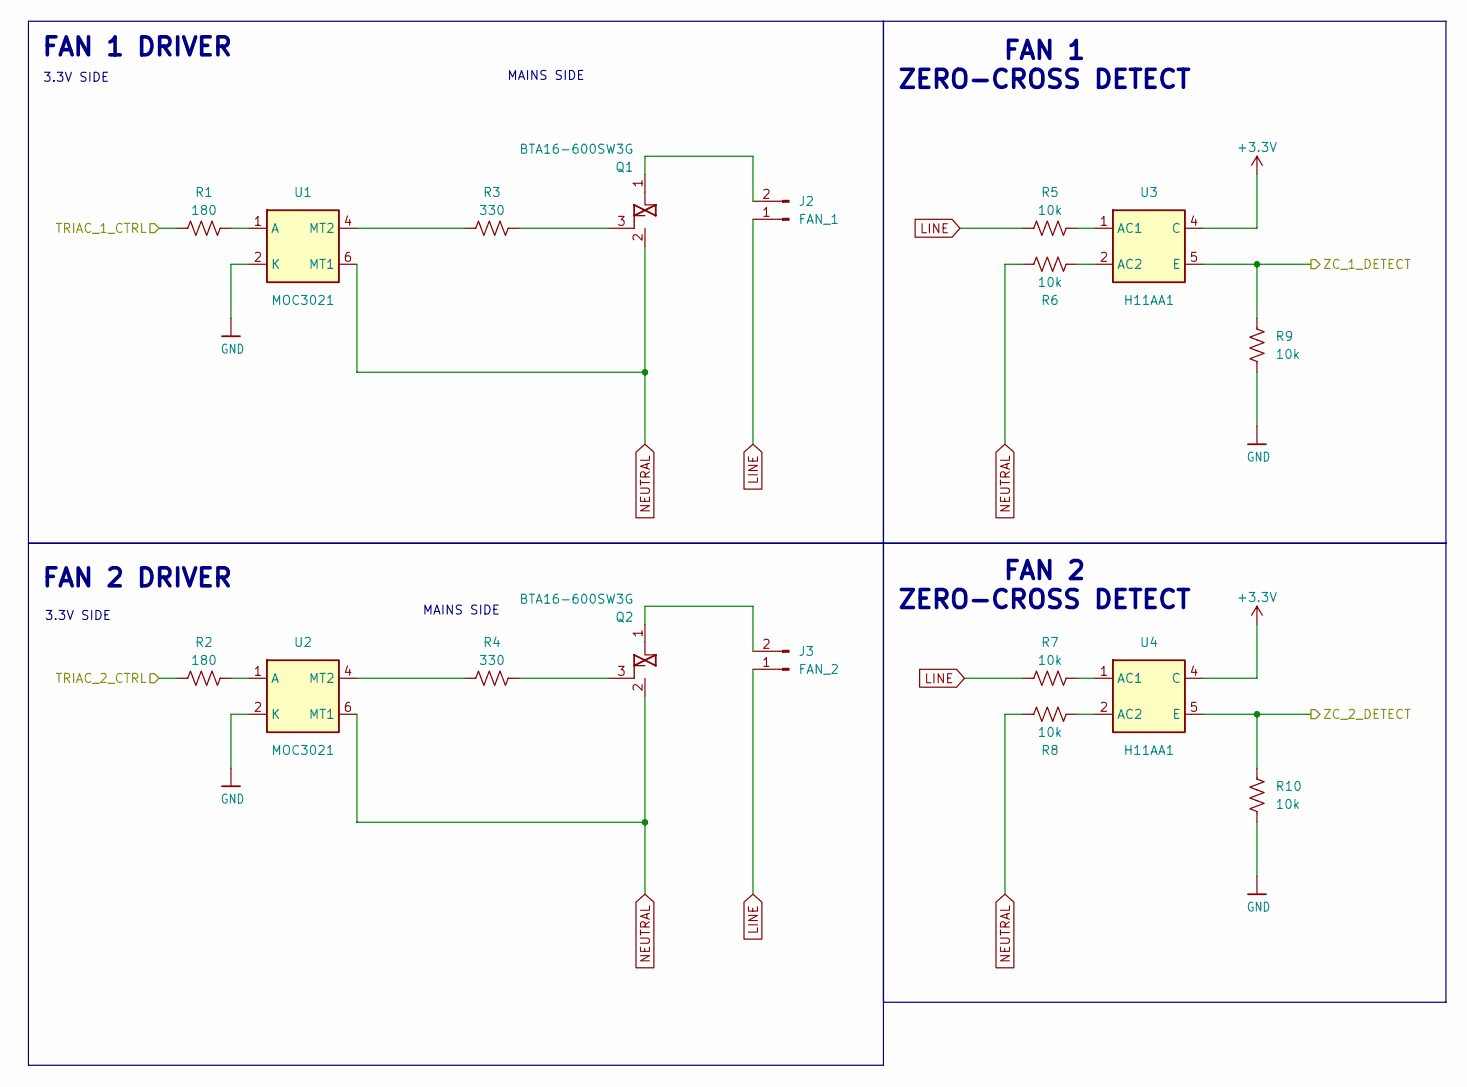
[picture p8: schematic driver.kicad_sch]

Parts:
J2: FAN_1; TerminalBlock_Phoenix_MKDS-1,5-2-5.08_1x02_P5.08mm_Horizont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
J3: FAN_2; TerminalBlock_Phoenix_MKDS-1,5-2-5.08_1x02_P5.08mm_Horizont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
Q1, Q2: BTA16-600SW3G; TO-220-3_Vertical
R1, R2: 180; R_0805_2012Metric
R3, R4: 330; R_0805_2012Metric
R5, R6, R7, R8, R9, R10: 10k; R_0805_2012Metric
U1, U2: MOC3021; DIP-6_W7.62mm
U3, U4: H11AA1; DIP-6_W7.62mm

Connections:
+3.3V: U3.4 (C), U4.4 (C)
/mcu/TRIAC_1_CTRL: R1.1; also elsewhere on the board
/mcu/TRIAC_2_CTRL: R2.1; also elsewhere on the board
/mcu/ZC_1_DETECT: R9.1, U3.5 (E); also elsewhere on the board
/mcu/ZC_2_DETECT: R10.1, U4.5 (E); also elsewhere on the board
GND: R9.2, R10.2, U1.2 (K), U2.2 (K); also elsewhere on the board
LINE: J2.1, J3.1, R5.1, R7.1; also elsewhere on the board
NEUTRAL: Q1.2 (MT1), Q2.2 (MT1), R6.1, R8.1, U1.6 (MT1), U2.6 (MT1)
unnamed: J2.2, Q1.1 (MT2)
unnamed: J3.2, Q2.1 (MT2)
unnamed: Q1.3 (G), R3.2
unnamed: Q2.3 (G), R4.2
unnamed: R1.2, U1.1 (A)
unnamed: R3.1, U1.4 (MT2)
unnamed: R2.2, U2.1 (A)
unnamed: R4.1, U2.4 (MT2)
unnamed: R5.2, U3.1 (AC1)
unnamed: R6.2, U3.2 (AC2)
unnamed: R7.2, U4.1 (AC1)
unnamed: R8.2, U4.2 (AC2)

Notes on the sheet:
FAN 1 ZERO-CROSS DETECT
MAINS SIDE
FAN 2 DRIVER
3.3V SIDE
FAN 2 ZERO-CROSS DETECT
FAN 1 DRIVER

Board: 2 copper layers, 46 parts (1 on the bottom side), 40 nets, no tracks yet.

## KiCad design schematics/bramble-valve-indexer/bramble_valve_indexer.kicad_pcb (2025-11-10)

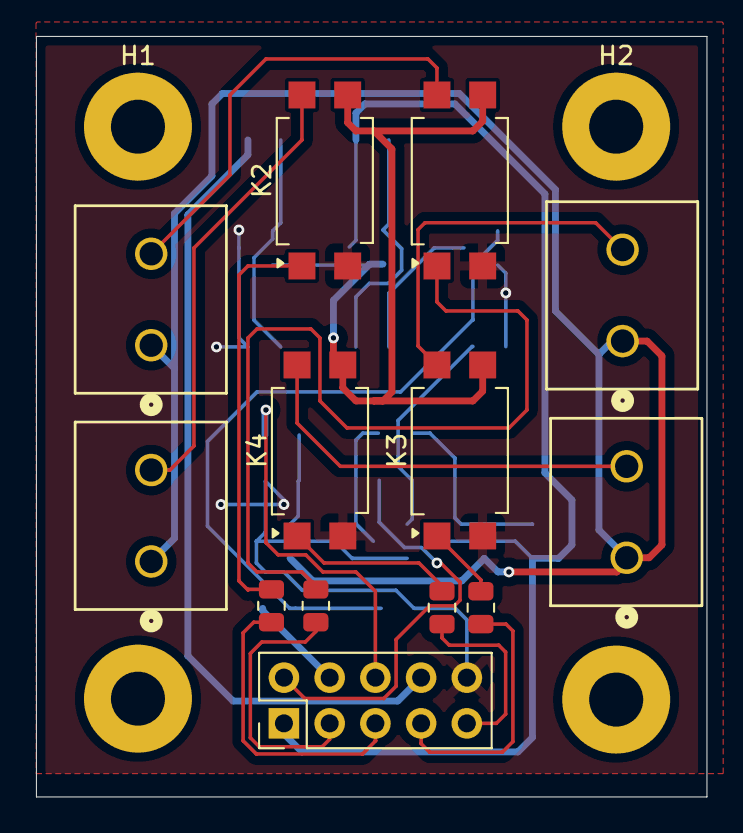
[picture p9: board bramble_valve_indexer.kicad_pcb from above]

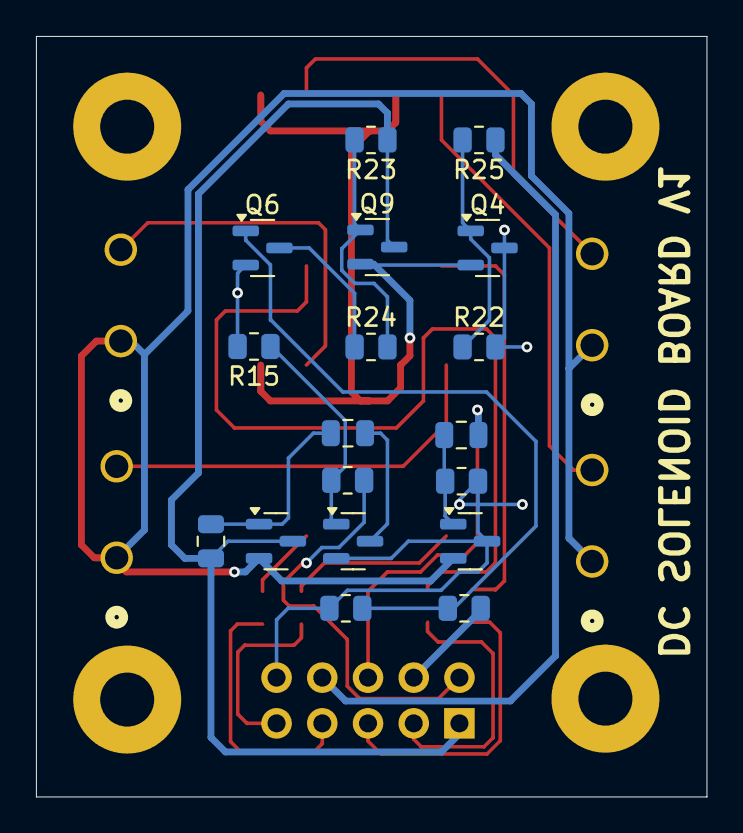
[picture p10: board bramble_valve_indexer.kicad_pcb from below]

Board: 2 copper layers, 37.2 x 42.2 mm, 35 parts (18 on the bottom side), 28 nets.

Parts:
H1, H2, H3, H4: MountingHole; MountingHole_3mm_Pad
J1: Conn_02x05_Odd_Even; PinHeader_2x05_P2.54mm_Vertical
K1, K2, K3, K4: VOR1142B4; SSO-4_6.7x5.1mm_P2.54mm_Clearance8mm
M1, M2, M3, M4: 1729128; CONN_1729128_PXC
Q2, Q4, Q6, Q8: DMN3300U; SOT-23
Q7, Q9: FDN360P; SOT-23
R12, R13, R20, R21: 170; R_0805_2012Metric
R14, R24, R25, R27: 100; R_0805_2012Metric
R15, R19, R22, R23, R26: 10k; R_0805_2012Metric
R16, R17: 100; C_0805_2012Metric
R18: 10k; C_0805_2012Metric

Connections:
+9V: J1.1, Q7.3 (D), Q9.3 (D), R18.1, R23.1
/M+: M1.1, M2.1, M3.1, M4.1, Q2.2 (S), Q7.2 (S)
/M-: K1.3, K2.3, K3.3, K4.3, Q4.2 (S), Q9.2 (S)
/MOTOR_HI_1: J1.2, R14.2
/MOTOR_HI_2: J1.4, R27.1
/MOTOR_LO_1: J1.6, R17.2
/MOTOR_LO_2: J1.8, R25.1
/VALVE_1: J1.3, R12.1
/VALVE_2: J1.5, R13.1
/VALVE_3: J1.7, R20.1
/VALVE_4: J1.9, R21.1
GND: J1.10, K1.2, K2.2, K3.2, K4.2, Q2.3 (D), Q4.3 (D), Q6.2 (S), Q8.2 (S), R15.2, R19.2, R22.2, R26.2
unnamed: K1.1, R12.2
unnamed: K1.4, M1.2
unnamed: K2.1, R13.2
unnamed: K2.4, M2.2
unnamed: K3.1, R20.2
unnamed: K3.4, M3.2
unnamed: K4.1, R21.2
unnamed: K4.4, M4.2
unnamed: Q2.1 (G), R17.1, R19.1
unnamed: Q4.1 (G), R22.1, R25.2
unnamed: Q6.3 (D), R24.1
unnamed: Q6.1 (G), R26.1, R27.2
unnamed: Q7.1 (G), R16.1, R18.2
unnamed: Q8.3 (D), R16.2
unnamed: Q8.1 (G), R14.1, R15.1
unnamed: Q9.1 (G), R23.2, R24.2

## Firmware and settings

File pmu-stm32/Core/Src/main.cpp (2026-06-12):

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
/* Includes ------------------------------------------------------------------*/
#include "main.h"

/* USER CODE BEGIN Includes */
#include "dcdc.h"
#include "fram.h"
#include "led.h"
#include "persistent_storage.h"
#include "pmu_protocol.h"
#include "pmu_state_machine.h"
/* USER CODE END Includes */

UART_HandleTypeDef hlpuart1;

RTC_HandleTypeDef hrtc;

TIM_HandleTypeDef htim21;

I2C_HandleTypeDef hi2c1;

/* USER CODE BEGIN PV */
LED led(GPIOA, GPIO_PIN_5);
DCDC dcdc;

// FRAM and persistent storage
static FRAM fram(hi2c1);
static PersistentStorage storage(fram);

// UART receive buffer
static uint8_t uartRxByte;

// ISR-to-main-loop flags
// All state machine events are dispatched from the main loop, never from ISR
// context, to avoid stack overflow on this 2KB RAM MCU.
static volatile bool rtcWakeupFlag = false;
static volatile bool readyForSleepFlag = false;
static volatile bool bootCompleteFlag = false;
static volatile bool valveTimerFlag = false;
volatile int buttonWakeFlag = 0;

// Valve timer state (set when configuring Alarm A, read on alarm fire)
static uint8_t valveTimerValveId = 0;
static bool valveTimerActive = false;

// Clock source fallback flag - set if LSE crystal fails to start
static bool usingLSIFallback = false;

// Boot animation parameters
namespace BootAnimationConfig {
constexpr int TOTAL_FLICKERS = 5;  // 5 flickers = 1 second total
constexpr uint32_t FLICKER_ON_MS = 100;
constexpr uint32_t FLICKER_OFF_MS = 100;
}  // namespace BootAnimationConfig

// Boot animation state (for non-blocking animation)
static struct {
    int flickerCount = 0;
    uint32_t lastToggleTime = 0;
    bool ledOn = false;
    bool complete = false;
} bootAnimation;

// Protocol callbacks
static void uartSendCallback(const uint8_t *data, uint8_t length);
static void setWakeIntervalCallback(uint32_t seconds);
static void keepAwakeCallback(uint16_t seconds);
static void readyForSleepCallback();
static uint32_t getTickCallback();
static void setValveTimerCallback(uint16_t durationSeconds, uint8_t valveId);

// Protocol instance
static PMU::Protocol protocol(uartSendCallback, setWakeIntervalCallback, keepAwakeCallback,
                              readyForSleepCallback, getTickCallback);

// PMU state machine instance
static PmuStateMachine pmuState(getTickCallback);
/* USER CODE END PV */

void SystemClock_Config(void);
static void MX_GPIO_Init(void);
static void MX_LPUART1_UART_Init(void);
static void MX_RTC_Init(void);
static void MX_TIM21_Init(void);
static void MX_I2C1_Init(void);
/* USER CODE BEGIN PFP */
static void configureRTCWakeup(uint32_t seconds);
static void configureValveCloseAlarm(uint16_t durationSeconds, uint8_t valveId);
static void enterStopMode(void);
static void wakeupFromStopMode(void);
static void determineWakeType(void);
static void startBootAnimation(void);
static void updateLedForState(PmuState state, WakeType wakeType);
static void onStateChange(PmuState newState);
static void sendWakeNotification();
/* USER CODE END PFP */

/**
 * @brief  The application entry point.
 * @retval int
 */
int main(void)
{
    /* MCU Configuration--------------------------------------------------------*/

    /* Reset of all peripherals, Initializes the Flash interface and the Systick. */
    HAL_Init();

    /* USER CODE BEGIN Init */
    // Capture why the PMU reset before anything else can clear the flags. A power-on
    // (PORRSTF) or NRST-button press (PINRSTF) is treated as a deliberate request to
    // force-close all valves to a known state; a software reset (reboot/factory cmd)
    // or watchdog reset is a warm restart that preserves valve state. Note: a power-on
    // also asserts PINRSTF, but both map to "reset valves" so the OR is fine.
    bool valveResetFromReset = (__HAL_RCC_GET_FLAG(RCC_FLAG_PORRST) != RESET) ||
                               (__HAL_RCC_GET_FLAG(RCC_FLAG_PINRST) != RESET);
    __HAL_RCC_CLEAR_RESET_FLAGS();

    /* USER CODE END Init */

    /* Configure the system clock */
    SystemClock_Config();

    /* Update SystemCoreClock variable after clock configuration */
    SystemCoreClockUpdate();

    /* Reconfigure SysTick with updated clock frequency */
    HAL_InitTick(TICK_INT_PRIORITY);

    /* Enable global interrupts explicitly */
    __enable_irq();

    /* Initialize all configured peripherals */
    MX_GPIO_Init();
    MX_LPUART1_UART_Init();
    MX_RTC_Init();
    MX_TIM21_Init();
    MX_I2C1_Init();

    /* USER CODE BEGIN 2 */
    // Start UART receive interrupt IMMEDIATELY after UART init
    // This ensures PMU is ready to receive commands as early as possible
    HAL_UART_Receive_IT(&hlpuart1, &uartRxByte, 1);

    led.init();
    led.off();

    // Initialize FRAM and persistent storage
    // Return values intentionally ignored — system operates in degraded mode without FRAM
    fram.init();
    storage.init();

    // Give the protocol layer access to persistent storage
    protocol.setStorage(&storage);

    // Register valve timer callback for RTC Alarm A
    protocol.setValveTimerCallback(setValveTimerCallback);

    // Load persisted state from FRAM (wake interval, schedules, node state)
    protocol.loadFromStorage();

    // Tell the protocol whether this boot was a power-on / NRST-button reset, so the
    // next wake notification asks the node to force-close valves (one-shot).
    protocol.setValveResetPending(valveResetFromReset);

    // Initialize DC/DC converter
    dcdc.init();
    dcdc.enable();

    // Set up state machine callback for LED updates
    pmuState.setStateCallback(onStateChange);

    // Configure RTC wakeup timer with wake interval (loaded from FRAM or default)
    configureRTCWakeup(protocol.getWakeInterval());

    // Start non-blocking boot animation (timer-based)
    // BOOT_COMPLETE is dispatched by timer callback when animation finishes
    // Main loop runs immediately, so CTS can be handled without waiting
    startBootAnimation();

    /* USER CODE END 2 */

    /* Infinite loop */
    /* USER CODE BEGIN WHILE */

    while (1) {
        /* USER CODE END WHILE */

        /* USER CODE BEGIN 3 */

        // =====================================================================
        // Event Processing
        // =====================================================================
        if (bootCompleteFlag) {
            bootCompleteFlag = false;
            pmuState.dispatch(PmuEvent::BOOT_COMPLETE);
        }

        if (buttonWakeFlag) {
            buttonWakeFlag = 0;
            pmuState.dispatch(PmuEvent::BUTTON_WAKE);
        }

        if (valveTimerFlag) {
            valveTimerFlag = false;
            // Valve close alarm fired — re-enable periodic wake timer
            uint32_t interval = protocol.getWakeInterval();
            if (interval > 0) {
                configureRTCWakeup(interval);
            }
            // Set wake type before dispatching so determineWakeType() won't override it
            pmuState.setWakeType(WakeType::VALVE_TIMER);
            pmuState.dispatch(PmuEvent::RTC_WAKEUP);
        }

        if (rtcWakeupFlag) {
            rtcWakeupFlag = false;
            pmuState.dispatch(PmuEvent::RTC_WAKEUP);
        }

        // Dispatch any RX frame parsed by the UART ISR. Done in main-loop context
        // so the (blocking) UART TX of the ACK/response doesn't starve RX.
        protocol.processPendingMessage();

        if (protocol.isCtsReceived()) {
            pmuState.dispatch(PmuEvent::CTS_RECEIVED);
            protocol.clearCtsReceived();
        }

        if (readyForSleepFlag) {
            readyForSleepFlag = false;
            pmuState.dispatch(PmuEvent::READY_FOR_SLEEP);
        }

        pmuState.tick();

        // =====================================================================
        // Output Control (pure - no side effects except outputs)
        // =====================================================================
        PmuState state = pmuState.state();
        updateLedForState(state, pmuState.wakeType());

        switch (state) {
            case PmuState::BOOTING:
                // Boot animation handled before loop
                break;

            case PmuState::POST_BOOT:
            case PmuState::AWAITING_CTS:
            case PmuState::WAKE_ACTIVE:
                dcdc.enable();
                break;

            case PmuState::SLEEPING:
#ifdef PMU_BRINGUP_MODE
                // Bringup mode: keep DC/DC on, skip sleep for development
                dcdc.enable();
#else
                dcdc.disable();
                enterStopMode();
                wakeupFromStopMode();
#endif
                break;

            case PmuState::ERROR:
            default:
                dcdc.disable();
                break;
        }
    }
    /* USER CODE END 3 */
}

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
/* USER CODE BEGIN 4 */

/**
 * @brief I2C1 Initialization Function (for FRAM)
 * 100 kHz standard mode on PA9 (SCL) / PA10 (SDA)
 */
static void MX_I2C1_Init(void)
{
    hi2c1.Instance = I2C1;
    hi2c1.Init.Timing = 0x00000909;  // ~105 kHz at 2.097 MHz PCLK1 (MSI range 5)
    hi2c1.Init.OwnAddress1 = 0;
    hi2c1.Init.AddressingMode = I2C_ADDRESSINGMODE_7BIT;
    hi2c1.Init.DualAddressMode = I2C_DUALADDRESS_DISABLE;
    hi2c1.Init.OwnAddress2 = 0;
    hi2c1.Init.GeneralCallMode = I2C_GENERALCALL_DISABLE;
    hi2c1.Init.NoStretchMode = I2C_NOSTRETCH_DISABLE;

    if (HAL_I2C_Init(&hi2c1) != HAL_OK) {
        Error_Handler();
    }
}

/**
 * @brief Initialize TIM21 for boot animation
 * Timer fires every 100ms for LED toggle
 */
static void MX_TIM21_Init(void)
{
    __HAL_RCC_TIM21_CLK_ENABLE();

#ifdef USE_WS2812
    // HSI clock is 16 MHz
    // For 100ms period: 16000000 / (1600 * 1000) = 10 Hz
    // Prescaler of 1599 (divide by 1600) -> 10000 Hz
    // Period of 999 (1000 counts) -> 100ms
    htim21.Instance = TIM21;
    htim21.Init.Prescaler = 1599;
#else
    // MSI clock is 2.097 MHz (range 5)
    // For 100ms period: 2097000 / 100 = 20970 counts per 100ms
    // Use prescaler of 209 (divide by 210) -> 9985.7 Hz
    // Period of 999 (1000 counts) -> 100.1ms (close enough)
    htim21.Instance = TIM21;
    htim21.Init.Prescaler = 209;
#endif
    htim21.Init.CounterMode = TIM_COUNTERMODE_UP;
    htim21.Init.Period = 999;
    htim21.Init.ClockDivision = TIM_CLOCKDIVISION_DIV1;
    htim21.Init.AutoReloadPreload = TIM_AUTORELOAD_PRELOAD_DISABLE;

    if (HAL_TIM_Base_Init(&htim21) != HAL_OK) {
        Error_Handler();
    }

    // Enable timer interrupt
    HAL_NVIC_SetPriority(TIM21_IRQn, 1, 0);
    HAL_NVIC_EnableIRQ(TIM21_IRQn);
}

/**
 * @brief Start non-blocking boot animation
 * Uses TIM21 interrupt to toggle LED
 */
static void startBootAnimation(void)
{
    bootAnimation.flickerCount = 0;
    bootAnimation.ledOn = true;
    bootAnimation.complete = false;

    // Start with LED on
    led.setColor(LED::GREEN);

    // Start timer
    HAL_TIM_Base_Start_IT(&htim21);
}

/**
 * @brief TIM21 interrupt handler
 */
extern "C" void TIM21_IRQHandler(void)
{
    HAL_TIM_IRQHandler(&htim21);
}

/**
 * @brief Timer period elapsed callback - handles boot animation
 */
void HAL_TIM_PeriodElapsedCallback(TIM_HandleTypeDef *htim)
{
    if (htim->Instance != TIM21 || bootAnimation.complete) {
        return;
    }

    if (bootAnimation.ledOn) {
        // LED was on, turn it off
        led.off();
        bootAnimation.ledOn = false;
        bootAnimation.flickerCount++;

        // Check if animation complete
        if (bootAnimation.flickerCount >= BootAnimationConfig::TOTAL_FLICKERS) {
            bootAnimation.complete = true;
            HAL_TIM_Base_Stop_IT(&htim21);
            bootCompleteFlag = true;
        }
    } else {
        // LED was off, turn it on
        led.setColor(LED::GREEN);
        bootAnimation.ledOn = true;
    }
}

/**
 * @brief Configure RTC wakeup timer
 * @param seconds Number of seconds between wakeups
 */
static void configureRTCWakeup(uint32_t seconds)
{
    // Disable wakeup timer first
    HAL_RTCEx_DeactivateWakeUpTimer(&hrtc);

    // Wait for WUTWF flag to be set (wakeup timer configuration allowed)
    // This is critical - without it, the SetWakeUpTimer call will hang
    // Use cycle-counting delay (~1ms per iteration at 16 MHz) instead of
    // HAL_Delay, since this function may be called from UART ISR context
    // (via setWakeIntervalCallback) where SysTick cannot fire
    uint32_t timeout = 1000;
    while (!__HAL_RTC_WAKEUPTIMER_GET_FLAG(&hrtc, RTC_FLAG_WUTWF) && timeout > 0) {
        timeout--;
        for (volatile uint32_t i = 0; i < 4000; i++) {}  // ~1ms at 16 MHz
    }

    if (timeout == 0) {
        // WUTWF flag never set - RTC is not ready for configuration
        return;
    }

    // Enable RTC interrupt in NVIC
    HAL_NVIC_SetPriority(RTC_IRQn, 0, 0);
    HAL_NVIC_EnableIRQ(RTC_IRQn);

    // Enable EXTI line 20 (RTC wakeup) for waking from STOP mode
    __HAL_RTC_WAKEUPTIMER_EXTI_ENABLE_IT();
    __HAL_RTC_WAKEUPTIMER_EXTI_ENABLE_RISING_EDGE();

    // Use ck_spre (1 Hz clock) for wakeup timer
    // This allows up to 65535 seconds (~18 hours) with 16-bit counter
    // The counter value is N-1 because it counts from N-1 down to 0
    uint32_t wakeupCounter;

    if (seconds > 65536) {
        // Clamp to maximum (counter goes 0-65535, which is 65536 values)
        wakeupCounter = 65535;
    } else if (seconds > 0) {
        wakeupCounter = seconds - 1;
    } else {
        // Minimum 1 second (counter = 0 means 1 tick)
        wakeupCounter = 0;
    }

    // Enable wakeup timer with interrupt using 1 Hz clock
    if (HAL_RTCEx_SetWakeUpTimer_IT(&hrtc, wakeupCounter, RTC_WAKEUPCLOCK_CK_SPRE_16BITS) !=
        HAL_OK) {
        // Flash LED to indicate error but don't halt
        led.setColor(LED::RED);
        HAL_Delay(2000);
        led.off();
    }
}

/**
 * @brief Configure RTC Alarm A for valve auto-close after a duration
 * @param durationSeconds Seconds until valve should be closed
 * @param valveId Which valve to close when alarm fires
 *
 * Uses RTC Alarm A (independent from the periodic Wakeup Timer).
 * The alarm fires once, waking the system from STOP mode via EXTI line 17.
 */
static void configureValveCloseAlarm(uint16_t durationSeconds, uint8_t valveId)
{
    // Store valve ID for the callback
    valveTimerValveId = valveId;

    // Deactivate any existing alarm first
    HAL_RTC_DeactivateAlarm(&hrtc, RTC_ALARM_A);

    // Read current RTC time
    RTC_TimeTypeDef currentTime;
    RTC_DateTypeDef currentDate;
    HAL_RTC_GetTime(&hrtc, &currentTime, RTC_FORMAT_BIN);
    HAL_RTC_GetDate(&hrtc, &currentDate, RTC_FORMAT_BIN);

    // Compute alarm time = now + duration
    uint32_t totalSeconds = currentTime.Hours * 3600 + currentTime.Minutes * 60 +
                            currentTime.Seconds + durationSeconds;

    uint8_t alarmHours = (totalSeconds / 3600) % 24;
    uint8_t alarmMinutes = (totalSeconds % 3600) / 60;
    uint8_t alarmSeconds = totalSeconds % 60;

    // Configure Alarm A to match hours, minutes, and seconds
    RTC_AlarmTypeDef alarm = {};
    alarm.AlarmTime.Hours = alarmHours;
    alarm.AlarmTime.Minutes = alarmMinutes;
    alarm.AlarmTime.Seconds = alarmSeconds;
    alarm.AlarmTime.SubSeconds = 0;
    alarm.AlarmTime.DayLightSaving = RTC_DAYLIGHTSAVING_NONE;
    alarm.AlarmTime.StoreOperation = RTC_STOREOPERATION_RESET;
    alarm.AlarmMask = RTC_ALARMMASK_DATEWEEKDAY;  // Match H:M:S only, ignore date
    alarm.AlarmSubSecondMask = RTC_ALARMSUBSECONDMASK_ALL;
    alarm.Alarm = RTC_ALARM_A;

    // Enable Alarm A EXTI line 17 for STOP mode wakeup
    __HAL_RTC_ALARM_EXTI_ENABLE_IT();
    __HAL_RTC_ALARM_EXTI_ENABLE_RISING_EDGE();

    if (HAL_RTC_SetAlarm_IT(&hrtc, &alarm, RTC_FORMAT_BIN) != HAL_OK) {
        led.setColor(LED::RED);
        HAL_Delay(500);
        led.off();
        return;
    }

    valveTimerActive = true;

    // Leave the periodic wake timer running — node can still check in with the hub
    // during a watering cycle (so commands like abort/override can interrupt).
}

/**
 * @brief RTC Alarm A event callback
 * Called when Alarm A fires (valve close timer expired).
 */
void HAL_RTC_AlarmAEventCallback(RTC_HandleTypeDef *hrtc)
{
    valveTimerFlag = true;
    valveTimerActive = false;
}

/**
 * @brief Enter STOP mode for low power sleep
 */
static void enterStopMode(void)
{
    // Enable LPUART wakeup from STOP mode (sets UESM bit in CR1)
    HAL_UARTEx_EnableStopMode(&hlpuart1);

    // Enable clock request in STOP mode (UCESM bit in CR3)
    // This allows LPUART to request HSI clock when START bit is detected
    SET_BIT(hlpuart1.Instance->CR3, USART_CR3_UCESM);

    // De-init I2C before sleep to avoid current draw on PA9/PA10
    HAL_I2C_DeInit(&hi2c1);

    // Suspend SysTick to prevent wakeup
    HAL_SuspendTick();

    // Enter STOP mode with low power regulator
    // Wake on any interrupt (RTC wakeup or LPUART in our case)
    HAL_PWR_EnterSTOPMode(PWR_LOWPOWERREGULATOR_ON, PWR_STOPENTRY_WFI);
}

/**
 * @brief Re-initialize system after waking from STOP mode
 */
static void wakeupFromStopMode(void)
{
    // Disable LPUART STOP mode after waking
    HAL_UARTEx_DisableStopMode(&hlpuart1);

    // After waking from STOP, system clock is MSI at reset speed
    // Need to reconfigure to our desired clock
    SystemClock_Config();

    // Resume SysTick
    HAL_ResumeTick();

    // Re-init LPUART against the post-wake clock. The baud-rate divisor was
    // computed at boot when the clock came from MSI; after SystemClock_Config()
    // the clock source/freq has changed, so the divisor needs recomputing or
    // bytes arrive at the wrong baud and frame/dropped intermittently.
    HAL_UART_DeInit(&hlpuart1);
    MX_LPUART1_UART_Init();

    // Re-arm UART RX interrupt
    HAL_UART_Receive_IT(&hlpuart1, &uartRxByte, 1);

    // Re-init I2C after wakeup
    MX_I2C1_Init();
}

/**
 * @brief Determine wake type from RTC time and schedule
 * Called by onStateChange callback when entering AWAITING_CTS state.
 * Sets wake type in state machine and applies appropriate boot delay.
 */
static void determineWakeType(void)
{
    // Clear dedup buffer for new boot cycle - HAL tick was suspended during STOP mode
    // so old sequence numbers may still appear "recent"
    protocol.clearDedupBuffer();

    // Reset CTS flag for this wake cycle
    protocol.clearCtsReceived();

    // Don't override wake type if already set (e.g. VALVE_TIMER set before dispatch)
    if (pmuState.wakeType() != WakeType::NONE) {
        return;
    }

    // Get current RTC time and date
    RTC_TimeTypeDef time;
    RTC_DateTypeDef date;
    HAL_RTC_GetTime(&hrtc, &time, RTC_FORMAT_BIN);
    HAL_RTC_GetDate(&hrtc, &date, RTC_FORMAT_BIN);

    // Check if this is a scheduled event by scanning FRAM entries
    PMU::ScheduleEntry entry;
    bool hasSchedule = protocol.getNextScheduledEntry(date.WeekDay, time.Hours, time.Minutes, entry);

    // Check if we're within the wake interval window of a scheduled event
    // This handles the case where RTC doesn't wake exactly at the scheduled time
    uint32_t wakeIntervalMinutes = protocol.getWakeInterval() / 60;

    if (hasSchedule &&
        entry.isWithinWindow(date.WeekDay, time.Hours, time.Minutes, wakeIntervalMinutes)) {
        // This is a scheduled watering event
        pmuState.setWakeType(WakeType::SCHEDULED, &entry);
    } else {
        // Normal periodic wake
        pmuState.setWakeType(WakeType::PERIODIC, nullptr);
    }

    // Small delay for RP2040 boot (scheduled needs more time)
    HAL_Delay(pmuState.wakeType() == WakeType::SCHEDULED ? 100 : 50);
}

/**
 * @brief RTC wakeup timer callback
 * This is called when the RTC wakeup interrupt fires
 * Keep this minimal to avoid stack overflow!
 */
void HAL_RTCEx_WakeUpTimerEventCallback(RTC_HandleTypeDef *hrtc)
{
    // Just set a flag - handle the actual work in main loop
    rtcWakeupFlag = true;
}

/**
 * @brief UART receive complete callback
 * Called when a byte is received via UART
 */
void HAL_UART_RxCpltCallback(UART_HandleTypeDef *huart)
{
    if (huart->Instance == LPUART1) {
        // Process received byte through protocol
        protocol.processReceivedByte(uartRxByte);

        // Re-enable interrupt for next byte
        HAL_UART_Receive_IT(&hlpuart1, &uartRxByte, 1);
    }
}

/**
 * @brief UART send callback for protocol
 */
static void uartSendCallback(const uint8_t *data, uint8_t length)
{
    HAL_UART_Transmit(&hlpuart1, (uint8_t *)data, length, 1000);
}

/**
 * @brief Set wake interval callback
 */
static void setWakeIntervalCallback(uint32_t seconds)
{
    // Reconfigure RTC wakeup timer with new interval
    // (configureRTCWakeup handles deactivation internally)
    configureRTCWakeup(seconds);
}

/**
 * @brief Valve timer callback - configures RTC Alarm A for valve auto-close
 */
static void setValveTimerCallback(uint16_t durationSeconds, uint8_t valveId)
{
    configureValveCloseAlarm(durationSeconds, valveId);
}

/**
 * @brief Keep awake callback
 * @param seconds Number of seconds to stay awake (resets wake timeout)
 */
static void keepAwakeCallback(uint16_t seconds)
{
    // Extend the PMU state machine's wake timeout
    // This resets the timer and sets a new timeout of 'seconds'
    // The RP2040 should call this periodically to stay awake indefinitely
    pmuState.extendWakeTimeout(seconds);
}

/**
 * @brief Get tick callback for protocol deduplication
 */
static uint32_t getTickCallback()
{
    return HAL_GetTick();
}

/**
 * @brief Ready for sleep callback - RP2040 signals work complete
 */
static void readyForSleepCallback()
{
    // Set flag for main loop — don't dispatch from ISR context
    readyForSleepFlag = true;
}
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

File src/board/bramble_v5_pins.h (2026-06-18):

#pragma once

/**
 * @file bramble_v5_pins.h
 * @brief Pin definitions for Bramble v5 board (custom RP2350B)
 *
 * v5 fixes the v4 PCB wiring defects:
 *   - LoRa MOSI/SCK no longer swapped — hardware SPI1 works directly
 *   - SX1262 DIO1 / BUSY routed natively (no bodge wires)
 *   - PMU UART RX on GPIO9 functional (no bodge to GPIO21)
 */

#include "hardware/i2c.h"
#include "hardware/spi.h"
#include "hardware/uart.h"

namespace Board {

// ==========================================================================
// Physical header definitions (GPIO numbers for each connector pin)
// Pin 1 = +3V3, Pin 2 = +9V, Pin 11 = VDD, Pin 12 = GND on all headers
// ==========================================================================

namespace J6 {                  // Motor/Valve connector (GPIO 28-35)
constexpr uint8_t PIN_3 = 35;   // VALVE_3
constexpr uint8_t PIN_4 = 34;   // MOTOR_LO_2
constexpr uint8_t PIN_5 = 33;   // VALVE_4
constexpr uint8_t PIN_6 = 32;   // MOTOR_LO_1
constexpr uint8_t PIN_7 = 31;   // VALVE_2
constexpr uint8_t PIN_8 = 30;   // MOTOR_HI_2
constexpr uint8_t PIN_9 = 29;   // VALVE_1
constexpr uint8_t PIN_10 = 28;  // MOTOR_HI_1
}  // namespace J6

namespace J7 {  // GPIO/debug header (GPIO 36-43)
constexpr uint8_t PIN_3 = 43;
constexpr uint8_t PIN_4 = 42;
constexpr uint8_t PIN_5 = 41;
constexpr uint8_t PIN_6 = 40;
constexpr uint8_t PIN_7 = 39;
constexpr uint8_t PIN_8 = 38;
constexpr uint8_t PIN_9 = 37;
constexpr uint8_t PIN_10 = 36;
}  // namespace J7

namespace J8 {  // General purpose header (GPIO 20-27)
constexpr uint8_t PIN_3 = 26;
constexpr uint8_t PIN_4 = 27;
constexpr uint8_t PIN_5 = 24;
constexpr uint8_t PIN_6 = 25;
constexpr uint8_t PIN_7 = 22;
constexpr uint8_t PIN_8 = 23;
constexpr uint8_t PIN_9 = 20;
constexpr uint8_t PIN_10 = 21;
}  // namespace J8

// ==========================================================================
// Functional pin assignments
// ==========================================================================

// --- LoRa (SX1262 / NiceRF LORA1262 on hardware SPI1) ---
// v5: PCB routes MOSI to GPIO15 and SCK to GPIO14 — matches SPI1 pin mux,
// so hardware SPI works directly (no bit-bang needed unlike v4).
inline auto LORA_SPI_PORT = spi1;
constexpr uint LORA_PIN_MISO = 12;  // SPI1 RX
constexpr uint LORA_PIN_SCK = 14;   // SPI1 SCK
constexpr uint LORA_PIN_MOSI = 15;  // SPI1 TX
constexpr uint LORA_PIN_CS = 10;    // GPIO chip-select (not hardware CSn)
constexpr uint LORA_PIN_RST = 16;
constexpr uint LORA_PIN_DIO1 = 19;
constexpr uint LORA_PIN_BUSY = 18;

// --- External flash (dedicated SPI0) ---
constexpr bool FLASH_HAS_DEDICATED_SPI = true;
inline auto FLASH_SPI_PORT = spi0;
constexpr uint FLASH_PIN_MISO = 0;
constexpr uint FLASH_PIN_SCK = 2;
constexpr uint FLASH_PIN_MOSI = 3;
constexpr uint FLASH_PIN_CS = 1;
constexpr uint FLASH_PIN_RST = 5;

// --- QSPI flash size (on-board) ---
constexpr uint32_t QSPI_FLASH_SIZE = 2 * 1024 * 1024;  // 2MB (W25Q16JV)

// --- NeoPixel ---
constexpr uint PIN_NEOPIXEL = 4;

// --- I2C (sensors) --- (J8 pins 3/4)
inline auto SENSOR_I2C_PORT = i2c1;
constexpr uint PIN_I2C_SDA = J8::PIN_3;  // GPIO 26
constexpr uint PIN_I2C_SCL = J8::PIN_4;  // GPIO 27

// --- Analog/digital inputs ---
constexpr uint PIN_A0 = J8::PIN_3;  // GPIO 26
constexpr uint PIN_A1 = J8::PIN_4;  // GPIO 27

// --- PMU UART (UART1 on GPIO8/9) ---
inline auto PMU_UART_PORT = uart1;
constexpr uint PMU_UART_TX_PIN = 8;
constexpr uint PMU_UART_RX_PIN = 9;

// --- Default stdio UART (UART0 on J6 header — no conflict with PMU on UART1) ---
constexpr int DEFAULT_UART = 0;
constexpr int DEFAULT_UART_TX_PIN = J6::PIN_10;  // GPIO 28 (UART0 TX)
constexpr int DEFAULT_UART_RX_PIN = J6::PIN_9;   // GPIO 29 (UART0 RX)

// --- API UART (hub ↔ Raspberry Pi / CM5) — UART0 on J6 (stdio is on USB CDC) ---
inline auto API_UART_PORT = uart0;
constexpr uint API_UART_TX_PIN = J6::PIN_10;  // GPIO 28
constexpr uint API_UART_RX_PIN = J6::PIN_9;   // GPIO 29

// --- Valve / Motor pins (J7 header) ---
// H-bridge pins are always defined (used by the DC latching path; unused in an
// AC build, where GPIO36/38 instead drive the two AC SSR gates directly).
constexpr uint8_t PIN_MOTOR_HI_1 = J7::PIN_10;  // GPIO 36
constexpr uint8_t PIN_MOTOR_HI_2 = J7::PIN_8;   // GPIO 38
constexpr uint8_t PIN_MOTOR_LO_1 = J7::PIN_6;   // GPIO 40
constexpr uint8_t PIN_MOTOR_LO_2 = J7::PIN_4;   // GPIO 42

#ifdef HARDWARE_IRRIGATION_AC
// AC variant: two AC valves switched by SSRs on GPIO36/38 (the H-bridge HI
// pins, repurposed as direct SSR gates). No indexer.
constexpr uint8_t NUM_VALVES = 2;
constexpr uint8_t VALVE_PINS[NUM_VALVES] = {
    36,  // VALVE_1 = SSR gate, silicon GPIO36
    38,  // VALVE_2 = SSR gate, silicon GPIO38
};
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

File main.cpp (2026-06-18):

/**
 * @file main.cpp
 * @brief Unified entry point for all Bramble hardware variants
 *
 * Creates the appropriate mode based on compile-time hardware configuration.
 */

#include <cstdio>
#include <cstring>
#include <functional>

#include "pico/stdlib.h"
#include "pico/unique_id.h"

#if LIB_PICO_STDIO_USB
#include "pico/stdio_usb.h"
#endif

#include "hardware/clocks.h"
#include "hardware/gpio.h"
#include "hardware/spi.h"
#include "hardware/structs/iobank0.h"
#include "hardware/timer.h"
#include "hardware/watchdog.h"

// HAL includes
#include "hal/flash.h"
#include "hal/logger.h"
#include "hal/neopixel.h"

// LoRa includes
#include "lora/address_manager.h"
#include "lora/hub_router.h"
#include "lora/message.h"
#include "lora/network_stats.h"
#include "lora/radio_interface.h"
#include "lora/reliable_messenger.h"
#ifdef RADIO_SX1262
#include "lora/sx1262.h"
#else
#include "lora/sx1276.h"
#endif

// Utility includes
#include "util/format.h"

// Configuration includes
#include "config/hub_config.h"
#include "config/node_config.h"
#include "version.h"

// Common mode includes
#include "modes/hub_mode.h"

// Mode includes based on hardware variant
#ifdef HARDWARE_CONTROLLER
#include "modes/controller_mode.h"
#elif HARDWARE_IRRIGATION
#include "modes/irrigation_mode.h"
#elif HARDWARE_SENSOR
#include "modes/sensor_mode.h"
#elif HARDWARE_GREENHOUSE
#include "modes/greenhouse_mode.h"
#else
#include "modes/application_mode.h"
#endif

#if defined(BOARD_V4) || defined(BOARD_V5)
#include "board/board_pins.h"
#ifdef BOARD_V4
#include "hal/bitbang_spi_device.h"
#else
#include "hal/spi_device.h"
#endif

// V4/V5: shared RP2350B layout — pins come from Board:: namespace.
// V4 uses bit-bang SPI (MOSI/SCK swapped on PCB); V5 uses hardware SPI1.
constexpr uint PIN_MISO = Board::LORA_PIN_MISO;
constexpr uint PIN_MOSI = Board::LORA_PIN_MOSI;
constexpr uint PIN_SCK = Board::LORA_PIN_SCK;
constexpr uint PIN_CS = Board::LORA_PIN_CS;
constexpr uint PIN_RST = Board::LORA_PIN_RST;
constexpr uint PIN_DIO1 = Board::LORA_PIN_DIO1;
constexpr uint PIN_BUSY = Board::LORA_PIN_BUSY;
constexpr uint PIN_NEOPIXEL = Board::PIN_NEOPIXEL;
constexpr uint PIN_A0 = Board::PIN_A0;
constexpr uint PIN_A1 = Board::PIN_A1;

#else  // V3
#include "hal/spi_device.h"

// Hardware configuration - Bramble board v3
static auto SPI_PORT = spi1;   // SPI1 for LoRa module
constexpr uint PIN_MISO = 8;   // SPI1 RX
constexpr uint PIN_SCK = 14;   // SPI1 SCK
constexpr uint PIN_MOSI = 15;  // SPI1 TX
constexpr uint PIN_CS = 16;    // GPIO as chip select
constexpr uint PIN_RST = 17;   // Reset pin
#ifdef RADIO_SX1262
constexpr uint PIN_DIO1 = 22;  // DIO1 interrupt pin (SX1262)
constexpr uint PIN_BUSY = 23;  // BUSY pin (SX1262)
#else
constexpr uint PIN_DIO0 = 21;  // DIO0 interrupt pin (SX1276 / RFM95W)
#endif
constexpr uint PIN_NEOPIXEL = 4;

// Controller input pins (Adafruit Feather RP2040)
constexpr uint PIN_A0 = 26;  // A0 analog/digital input
constexpr uint PIN_A1 = 27;  // A1 analog/digital input
#endif  // BOARD_V4 / BOARD_V5

// Demo mode configuration is set by CMake
// Debug UART: printf goes to GPIO12 (VALVE_3) via CMakeLists.txt config

/**
 * @brief Node configuration info for registration
 */
struct VariantInfo {
    uint8_t node_type;
    uint8_t capabilities;
    const char *variant_name;
};

/**
 * @brief Get variant info based on hardware variant
 * @return VariantInfo with type, capabilities, and name
 */
inline VariantInfo getVariantInfo()
{
#ifdef HARDWARE_IRRIGATION
    return {NODE_TYPE_HYBRID, CAP_VALVE_CONTROL | CAP_SOIL_MOISTURE, "Irrigation Node"};
#elif HARDWARE_SENSOR
    return {NODE_TYPE_SENSOR, CAP_TEMPERATURE | CAP_HUMIDITY, "Sensor Node"};
#elif HARDWARE_CONTROLLER
    return {NODE_TYPE_CONTROLLER, CAP_CONTROLLER | CAP_SCHEDULING, "Controller"};
#elif HARDWARE_GREENHOUSE
    return {NODE_TYPE_ACTUATOR, CAP_VALVE_CONTROL | CAP_TEMPERATURE | CAP_HUMIDITY,
            "Greenhouse Node"};
#else
    return {NODE_TYPE_SENSOR, 0, "Generic Node"};
#endif
}

// Forward declarations
bool initializeHardware(RadioInterface &lora, NeoPixel &led);
uint64_t getDeviceId();
bool attemptRegistration(ReliableMessenger &messenger, RadioInterface &lora,
                         NodeConfigManager &config_manager, uint64_t device_id);

/**
 * @brief Build the reregistration callback used by all modes.
 *
 * Resets the messenger to the unregistered address and resends a registration
 * request to the hub. Invoked when the hub signals PENDING_FLAG_REREGISTER.
 */
inline std::function<void()> makeReregistrationCallback(ReliableMessenger &messenger,
                                                        uint64_t device_id,
                                                        const VariantInfo &variant)
{
    return [&messenger, device_id, variant]() {
        printf("Re-registering with hub...\n");
        messenger.setNodeAddress(ADDRESS_UNREGISTERED);
        messenger.sendRegistrationRequest(ADDRESS_HUB, device_id, variant.node_type,
                                          variant.capabilities, BRAMBLE_FIRMWARE_VERSION,
                                          variant.variant_name);
    };
}

/**
 * @brief Main entry point
 *
 * Initializes hardware and starts the appropriate mode based on
 * compile-time configuration and role.
 */
int main()
{
    // Initialize stdio (UART configured via CMakeLists.txt)
    stdio_init_all();
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

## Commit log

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2025-09-12 Implement irrigation valve switcher with H-bridge control
    Features:
    - H-bridge driver for bidirectional 250ms pulses to DC latching solenoids
    - Valve indexer for selecting individual valves (4 valves supported)
    - High-level ValveController API with thread safety and state tracking
    - Integration with ProductionMode for actuator command handling
    - Callback mechanism in ReliableMessenger for message handling
    - GPIO allocation: H-bridge on pins 2,3,6,7, valves on pins 8,9,10,11
    - Extensible design ready for future AC valve support
    - Comprehensive error checking and logging
    [valve_controller.cpp, valve_controller.h]
2025-09-12 Update valve controller pin mapping for Feather RP2040
    - Changed H-bridge pins to use analog-capable GPIOs:
    - MOTOR_LO_1: GPIO26 (A0)
    - MOTOR_LO_2: GPIO27 (A1)
    - MOTOR_HI_1: GPIO28 (A2)
    - MOTOR_HI_2: GPIO29 (A3)
    - Updated valve count from 4 to 2 valves
    - Valve control pins now on GPIO24 and GPIO25
    - This avoids conflict with default I2C pins (GPIO2/3)
    [bramble.kicad_sch, pmu.kicad_sch, valve_indexer.kicad_sch]
2025-09-12 Implement hardware specialization architecture with working irrigation node
    - Replace bramble.cpp with unified main.cpp supporting multiple hardware variants
    - Add hardware specialization build system (IRRIGATION, CONTROLLER, SENSOR, GENERIC)
    - Create modular application mode architecture in src/modes/
    - Implement fully functional irrigation valve control system
    - Add H-bridge driver for DC latching solenoid valves
    - Add valve indexer for individual valve selection via MOSFETs
    - Fix critical section deadlocks by removing them (single-threaded operation)
    - Add proper LoRa interrupt mode initialization
    - Add missing hardware/timer.h include for timing functions
    - Add ValveController constructo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
    [main.cpp, sensor_mode.cpp, valve_controller.cpp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]
2025-10-10 Add STM32L010 PMU firmware with C++ LED control
    Implement initial firmware for STM32L010F4 power management unit with:
    - STM32 HAL initialization and clock configuration (MSI @ 2.1MHz)
    - Fixed SysTick interrupt setup with explicit interrupt enable
    - C++ LED control class supporting red, green, and orange colors
    - CMake build system with C++17 support
    - Common anode RGB LED abstraction
    Key implementation details:
    - Resolved HAL_Delay() hang by calling SystemCoreClockUpdate() after
    clock config and explicitly enabling interrupts with __enable_irq()
    - Created LED class with setColor(), blink(), and off() methods
    - Converted main.c to main.cpp for C++ support
    - Added proper extern "C" linkag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
    [main.cpp, main.h, pmu-stm32.ioc]
2025-10-10 Fix LED control for common cathode configuration
    Correct LED pin assignments and logic:
    - Swap RED (PA5) and GREEN (PA4) pin definitions
    - Update LED driver logic: HIGH = ON, LOW = OFF (common cathode)
    - Remove incorrect "common anode" comments
    Previously the code was written for common anode (LOW=ON), but the
    hardware uses common cathode where HIGH=ON.
    [main.h]
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2025-10-12 Add non-blocking ACK/NACK result callbacks to PMU protocol
    Replace fire-and-forget command pattern with callback-based result
    handling. Commands now accept an optional callback that receives the
    ACK/NACK result from the PMU.
    Changes:
    - Replace AckCallback/NackCallback with CommandResultCallback
    - Command functions now accept optional result callback
    - Callbacks receive (bool success, ErrorCode error)
    - Pending callback cleared after invocation
    - Updated irrigation mode to log command results
    Example usage:
    protocol.setWakeInterval(300, [](bool success, ErrorCode error) {
    if (success) {
    logger.info("Command succeeded");
    } else {
    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
    [main.cpp]
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2025-10-15 Add Python REST API for LoRa schedule management
    Implements Flask-based REST API that runs on Raspberry Pi and communicates
    with LoRa hub via serial to manage irrigation schedules remotely.
    - Node management endpoints (list, get, view queue)
    - Schedule management (add, remove irrigation schedules)
    - Wake interval configuration
    - Bidirectional serial communication with hub
    - Hub can query API for NTP-synchronized datetime
    - Comprehensive validation and error handling
    - Systemd service for auto-start on boot
    Tech stack:
    - Flask for REST API
    - pyserial for hub communication
    - uv for Python package management
    - NTP time synchronization on Raspberry Pi
    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
    [app.py, config.py, models.py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]
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2025-10-20 Add heartbeat-based time synchronization (Phases 1, 2, 6)
    Implement first half of time synchronization system allowing hub to respond
    to heartbeats with current datetime. Nodes will use this to sync their RTC.
    Message Protocol:
    - Add MSG_TYPE_HEARTBEAT_RESPONSE (0x0B) message type
    - Add HeartbeatResponsePayload with datetime fields (year, month, day, dotw, hour, min, sec)
    - Add sendHeartbeatResponse() to ReliableMessenger
    - Update MessageValidator to accept new message type
    Hub Time Management:
    - Hub initializes RP2040 RTC on startup
    - Hub requests time from RasPi via serial GET_DATETIME command
    - Hub syncs time hourly to correct drift
    - Hub responds to heartbeats with HEARTBEAT_RESPONSE c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
    [serial_interface.py]
2025-10-20 Fix serial interface initialization for time synchronization
    Initialize serial connection on API startup instead of waiting for first
    API call. This ensures the hub can immediately query datetime via UART.
    - Call get_serial() in main() before starting Flask app
    - Add logging to confirm serial connection established
    - Remove obsolete docker-compose version field
    Without this fix, the hub sends GET_DATETIME on startup but nobody is
    listening because SerialInterface.connect() was never called. The hub's
    RTC remains uninitialized and logs show milliseconds instead of datetime.
    Testing:
    - Verified serial connection works via test script
    - Confirms datetime response format: DATETIME YY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
    [app.py]
2025-10-20 Fix serial initialization for Flask debug mode with auto-reloader
    Flask's debug mode with auto-reload causes the app to restart after initial
    startup. The serial connection was being initialized in the parent process
    before the reload, so it never ran in the actual serving process.
    Fix: Check WERKZEUG_RUN_MAIN environment variable to only initialize serial
    in the reloader subprocess (or in production mode without reloader).
    [app.py]
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2025-11-02 fix: cancel pending REGISTRATION message on successful response
    - Modify sendRegistrationRequest() to return sequence number instead of bool
    - Add cancelPendingMessage() method to ReliableMessenger
    - Store registration sequence number in main.cpp
    - Cancel pending message when REG_RESPONSE received
    - Add messenger.update() call in registration wait loop to process queue
    This fixes the issue where REGISTRATION kept retrying even after receiving
    a successful REG_RESPONSE, because the pending message was never removed
    from the retry queue.
    [main.cpp]
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2026-01-09 Update pin config for Bramble v3 board
    - Change MISO from GPIO12 (v1 bodge) to GPIO8 (Feather-compatible)
    - Temporarily disable valve controller init for UART debug on GPIO24
    [main.cpp]
2026-01-10 Add CHT832X temperature/humidity sensor support for data logger
    Implement SensorMode for DFRobot SEN0546 (CHT832X) I2C sensor:
    - Add CHT832X HAL driver with I2C communication on GPIO26/27
    - Read temperature and humidity every 30 seconds
    - Transmit sensor data via LoRa to hub (fixed-point 0.01 units)
    - Send heartbeat every 60 seconds with CAP_TEMPERATURE | CAP_HUMIDITY
    - Cyan breathing LED pattern for sensor nodes
    - Add hardware_i2c library to CMakeLists.txt
    [cht832x.cpp, sensor_mode.cpp]
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2026-01-10 feat: integrate flash storage into sensor mode
    Connect sensor mode to flash storage layer:
    - Initialize external flash and flash buffer on startup
    - Write every sensor reading to flash BEFORE LoRa transmission
    - Add periodic backlog transmission task (configurable interval)
    - Implement batch transmission for untransmitted records
    - Add BACKLOG_TX_INTERVAL_MS configuration constant (5 minutes default)
    - Include sensor_flash_buffer.cpp in CMakeLists.txt build
    Note: Records stay untransmitted until ACK tracking is implemented.
    This ensures resilience but requires extending ReliableMessenger with
    ACK callbacks to mark records as transmitted and prevent perpetual
    retransmission.
    [sensor_mode.cpp]
2026-01-10 feat: add ACK callback system for flash record tracking
    Extend ReliableMessenger with callback mechanism to notify when ACKs are
    received, enabling sensor mode to mark flash records as transmitted:
    - Add AckCallback type and user_context field to PendingMessage
    - Implement sendWithCallback() and sendSensorDataWithCallback() methods
    - Invoke callbacks in handleAck() before removing from pending
    - Update sensor mode to use RELIABLE criticality with callbacks
    - Track flash write index and mark as transmitted on ACK
    This prevents perpetual retransmission of all sensor data by properly
    marking records as transmitted only after hub acknowledges receipt.
    Without ACK tracking, untransmitted record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
    [sensor_mode.cpp]
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2026-01-10 fix: only advance read_index after successful transmission ACK
    readUntransmittedRecords() was unconditionally advancing read_index after
    reading records, causing permanent data loss if transmission failed.
    - Remove read_index update from readUntransmittedRecords()
    - Add advanceReadIndex(count) method for caller to use after ACK
    - Update sensor_mode.cpp ACK callback to call advanceReadIndex()
    - Update docstrings to clarify the new behavior
    This ensures records are only skipped after successful delivery is confirmed.
    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
    [sensor_mode.cpp]
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2026-01-10 fix: handle circular buffer wraparound in batch transmission
    Record index calculation now uses modulo arithmetic to correctly handle
    wraparound at the circular buffer boundary. Without this fix, if
    start_index was near MAX_RECORDS, indices would overflow and mark
    incorrect records as transmitted.
    Example: start_index=MAX_RECORDS-5, count=10 would previously try to
    mark indices MAX_RECORDS through MAX_RECORDS+4 which are invalid.
    [sensor_mode.cpp]
2026-01-10 refactor: remove transmitted flag usage from hot path
    Simplify transmission tracking:
    - Real-time sensor sends now use BEST_EFFORT (no callback)
    - readUntransmittedRecords() only checks RECORD_FLAG_VALID
    - read_index advancement is sole mechanism for tracking progress
    - Timestamps enable deduplication if USB recovery needed
    The markTransmitted() function and RECORD_FLAG_TRANSMITTED constant
    are retained for potential debug/recovery tools but no longer used
    in normal operation. This eliminates flash wear from per-record
    flag updates.
    [sensor_mode.cpp]
2026-01-11 fix: address PR review feedback
    - Fix test assertions to use nested keys (temperature.min_celsius)
    - Rename temp_seq to temperature_sequence per naming convention
    - Rename node_addr to node_address per naming convention
    [database.py, sensor_mode.cpp]
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2026-01-12 feat: migrate sensor data API from SQLite to DuckDB
    - Replace sqlite3 with duckdb in database.py
    - Add WriteBuffer class for batching writes (DuckDB performs
    better with bulk operations)
    - Update SQL syntax: INSERT OR IGNORE -> ON CONFLICT DO NOTHING,
    TEXT -> VARCHAR, handle ID generation manually
    - Update config.py: change default path to .duckdb, add flush interval
    - Add duckdb>=0.10.0 dependency to pyproject.toml
    - Fix test fixture to delete temp file before DuckDB creates it
    All 9 existing tests pass.
    [config.py, database.py]
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2026-01-17 refactor(main): replace printf with Logger class
    Replace raw printf statements with structured Logger calls for
    consistent logging with timestamps, module names, and level filtering.
    - Add Logger instances in main(), initializeHardware(),
    attemptRegistration(), and processIncomingMessage()
    - Use log.info() for startup messages and success confirmations
    - Use log.debug() for diagnostic output (flash test, clocks, heartbeats)
    - Use log.warn() for warnings (registration timeout, polling fallback)
    - Use log.error() for errors (init failures)
    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
    [main.cpp]
2026-01-17 refactor: remove unused sleepUntilInterrupt function
    Power management is handled by the PMU turning off the RP2040 entirely,
    making CPU-level sleep optimization pointless. Replace the misleading
    function with a direct sleep_ms(10) call.
    [main.cpp]
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2026-01-17 refactor(main): extract flash test into separate function
    Move external flash test logic from main() into testExternalFlash()
    to improve readability. The function has its own logger and returns
    success/failure status.
    [main.cpp]
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2026-01-17 refactor: replace printf calls with Logger class
    Convert raw printf statements to use the Logger class for consistent,
    structured logging with timestamps and log levels across the codebase.
    - HAL layer: hbridge, valve_controller, valve_indexer, gpio_interrupt_manager,
    controller_inputs, pmu_protocol
    - Config layer: node_config
    - LoRa layer: sx1276, address_manager, hub_router
    - Modes layer: application_mode, production_mode, hub_mode, controller_mode
    Each file now uses appropriate log levels:
    - logger.error() for errors/failures
    - logger.warn() for warnings
    - logger.info() for status/informational messages
    - logger.debug() for verbose/debug output
    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
    [controller_inputs.cpp, gpio_interrupt_manager.cpp, valve_controller.cpp]
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2026-01-17 fix: port ExternalFlash driver to hardware SPI1 (#12)
    * fix: disable external flash driver to fix GPIO conflicts
    The ExternalFlash driver uses PIO bit-banging on GPIO 4-10, but the
    actual hardware has MT25 flash sharing SPI1 with LoRa:
    - MT25 MISO: GPIO8 (shared with LoRa)
    - MT25 SCK: GPIO14 (shared with LoRa)
    - MT25 MOSI: GPIO15 (shared with LoRa)
    - MT25 CS: GPIO6
    - MT25 RESET: GPIO7
    The incorrect pin config caused:
    - GPIO4 (NeoPixel) reconfigured as flash DQ2 → LED stuck
    - GPIO8 (LoRa MISO) reconfigured as flash SCK → SPI failures
    Disabled flash init until driver is rewritten for hardware SPI1.
    * docs: add pin configuration t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
    [external_flash.cpp, main.cpp, sensor_mode.cpp]
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2026-01-17 fix(api): use UBIGINT for device_id to support full 64-bit range
    Device IDs can exceed signed BIGINT max value (~9.2e18), causing
    DuckDB conversion errors when inserting sensor batch data. UBIGINT
    (unsigned 64-bit, max ~18.4e18) supports the full range of hardware
    device IDs.
    [database.py]
2026-01-17 feat(sensor): use Unix timestamps from RTC for sensor recordings
    - Add rtc_synced_ flag to track when RTC has received time from hub
    - Add getUnixTimestamp() helper to convert RTC datetime to Unix time
    - Send heartbeat immediately on sensor startup for time sync
    - Skip storing sensor data until RTC is synced
    - Use Unix timestamp from RTC instead of boot time for records
    [sensor_mode.cpp]
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2026-01-18 feat(led): add initialization pattern with RTC sync transition (#15)
    * feat(led): add initialization pattern with RTC sync transition
    Add orange blinking LED pattern during device initialization (waiting
    for RTC sync), automatically switching to the operational pattern once
    the hub responds with time.
    - Add BlinkingPattern class with configurable on/off timing
    - Add operational_pattern_ member to ApplicationMode base class
    - Call switchToOperationalPattern() in onHeartbeatResponse() after RTC sync
    - Sensor mode: orange blink -> purple breathing
    - Irrigation mode: orange blink -> green heartbeat
    * fix(irrigation): send immediate hear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
    [sensor_mode.cpp]
2026-01-18 Feature/pmu ready for sleep (#17)
    * feat(pmu): add ReadyForSleep command to PMU protocol
    Add ReadyForSleep (0x17) command for RP2040 to signal work completion
    to STM32. This allows proper coordination of power-down timing instead
    of fixed delays.
    STM32 side:
    - Add ReadyForSleep to Command enum
    - Add ReadyForSleepCallback type and handler
    - handleReadyForSleep() sends ACK then calls callback
    RP2040 side:
    - Add ReadyForSleep to Command enum
    - Add readyForSleep() method to Protocol class
    * feat(pmu): implement periodic wake state machine in STM32
    Replace fixed delay power-down with state machine that waits for
    RP2040 to signal ReadyF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
    [main.cpp, sensor_mode.cpp]
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2026-01-21 Claude/add led blink indicators i5p qw (#25)
    * feat(led): add power-efficient short blink patterns for nodes
    Replace heartbeat/breathing patterns with short blink patterns for
    sensor and irrigation nodes to optimize power usage:
    - Sensor nodes: red short blink (255,0,0)
    - Irrigation nodes: blue short blink (0,0,255)
    Add ShortBlinkPattern class with 50ms on / 3s off default timing.
    Add TransmitPattern class for TX activity indication (rapid white flash).
    * fix(led): reduce short blink off period to 500ms
    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
    [sensor_mode.cpp]
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2026-01-22 fix(sensor): initialize last_sync_timestamp on first boot (#34)
    On first boot (or after flash erase), last_sync_timestamp is 0, causing
    bogus elapsed time values and immediate transmission instead of waiting
    for the interval. Initialize it to current RTC time in onRtcSynced() to
    provide a valid baseline for interval comparison.
    [sensor_mode.cpp]
2026-01-22 Fix/init last sync timestamp (#37)
    * fix(sensor): initialize last_sync_timestamp on first boot
    * fix(sensor): always sync RTC from hub before batch transmission
    PMU RTC crystal drifts over time (14+ minutes observed). Previously when
    PMU had valid time, onRtcSynced() was called directly, triggering batch
    transmission with potentially drifted timestamps.
    Now the flow alwa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
    [sensor_mode.cpp]
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2026-01-23 Claude/analyze api loading performance 58q bi (#43)
    * docs(api): add performance optimization plan for chart loading
    Analyze and document plan to address slow API loading when viewing
    24-hour sensor charts. Key optimizations: time-filtered statistics,
    server-side downsampling, gzip compression, compact JSON responses.
    https://claude.ai/code/session_01RHei7kyx4KZhMYX9dpgekT
    * perf(api): optimize chart loading with compression and downsampling
    - Add Flask-Compress for automatic gzip compression (~70-80% reduction)
    - Add time filters to statistics query to avoid full table scans
    - Add server-side downsampling (bucket averaging) for chart data
    - Remove redundant fields from JSON response (us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
    [app.py, database.py]
2026-01-23 Claude/add task queue jbzpy (#39)
    * Add task queue design document
    Design for a lightweight internal task queue to replace scattered work
    coordination patterns (WorkTracker, deferred flags, multiple update calls).
    Key features:
    - Static allocation (16 slots, ~420 bytes RAM)
    - Priority levels (High/Normal/Low)
    - Delayed execution support
    - Task dependencies (postAfter)
    - Single process() call replaces multiple update loops
    * Implement TaskQueue for unified task coordination
    Add a lightweight, statically-allocated task queue to replace scattered
    work coordination patterns. Key features:
    - Static allocation (16 slots, ~420 bytes RAM)
    - Priority-based scheduling (High/Normal/Low)
    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
    [sensor_mode.cpp]
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2026-01-24 Feat/show rssi battery and status (#46)
    * feat(protocol): add error flag constants for node health conditions
    Define ERR_FLAG_* constants in message.h for heartbeat error reporting:
    - SENSOR_FAILURE: temp/humidity sensor not responding
    - FLASH_FAILURE: external flash not responding
    - FLASH_FULL: flash storage >90% full
    - PMU_FAILURE: PMU communication failure
    - BATTERY_LOW: battery <20%
    - BATTERY_CRITICAL: battery <10%
    - RTC_NOT_SYNCED: RTC never synchronized
    - RADIO_ISSUE: LoRa transmission issues
    * feat(firmware): implement error detection in sensor mode
    Add collectErrorFlags() and getBatteryLevel() methods to sensor mode:
    - Track sensor read validity for error reporting
    - Check flash s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
    [app.py, database.py, sensor_mode.cpp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]
2026-01-25 Feature/application mode state machine (#48)
    * Proactively send time from api -> hub
    * Keep trying to get RTC time from api
    * fix: race condition in sensor mode rtc sync
    * fix(sensor): report error when sensor fails to initialize
    Previously, ERR_FLAG_SENSOR_FAILURE was only set when sensor_initialized_
    was true AND last_sensor_read_valid_ was false. This meant if the sensor
    never initialized (I2C failure, wrong address, wiring issue), no error
    was ever reported in heartbeats.
    Added sensor_init_attempted_ flag to track initialization attempts.
    Now error_flags correctly reports sensor failure when:
    1. Init was attempted but failed
    2. Init succeeded but reads are failing
    * fix(sensor): ch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
    [sensor_mode.cpp]
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2026-01-26 fix(api): cap DuckDB memory to prevent OOM kills on Pi (#51)
    DuckDB defaults to 75% of system RAM, which causes the kernel OOM
    killer to terminate the API container on memory-constrained Pi devices.
    Caps memory at 128MB and threads at 2, configurable via environment.
    [config.py, database.py]
2026-01-26 Feature/sensor reliability improvements v2 (#52)
    * refactor(gpio): replace map with fixed-size array for interrupt handlers
    Use a fixed-size array indexed by GPIO pin number instead of std::map,
    removing heap allocation from ISR context. Also removes logging from
    the globalInterruptHandler since it runs in hardware interrupt context
    where USB/UART access is unsafe.
    * fix(lora): recover missed RX/TX interrupts via register polling
    Add checkForMissedRxInterrupt() that polls the IRQ flags register as a
    fallback when DIO0 GPIO interrupts are unreliable. Process pending
    interrupts in isTxDone() before checking the flag. Remove automatic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
    [external_flash.cpp, gpio_interrupt_manager.cpp, main.cpp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]
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2026-01-27 refactor: remove location field from node metadata (#55)
    Location was unused and redundant with zone-based organization.
    Removes from frontend (NodeNameEditor, NodeCard, types, API client)
    and backend (models, database queries, API endpoints).
    The column remains in existing DuckDB databases but is no longer
    read or written.
    [app.py, database.py, models.py]
2026-01-27 Fix/api memory stability (#56)
    * perf(api): use persistent DuckDB connection with cursor pooling
    Replace connect-per-operation pattern with a single persistent connection
    that hands out lightweight cursors. Eliminates repeated duckdb.connect()
    overhead and allows concurrent reads without blocking.
    * perf(api): stream CSV export to avoid memory spike
    Replace in-memory 100K-record CSV build with a row-at-a-time generator.
    Keeps memory constant regardless of export size.
    * fix(api): add Docker memory limits and worker DB config
    Add mem_limit to API (256m) and worker (128m) cont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
    [app.py, database.py]
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

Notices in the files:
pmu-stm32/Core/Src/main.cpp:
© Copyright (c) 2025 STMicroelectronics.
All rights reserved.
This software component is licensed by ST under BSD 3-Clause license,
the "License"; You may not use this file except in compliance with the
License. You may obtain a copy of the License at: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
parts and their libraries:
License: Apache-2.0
